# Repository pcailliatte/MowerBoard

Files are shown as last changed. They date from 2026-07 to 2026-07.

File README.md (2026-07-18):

# MowerBoard

<p align="center">
  
  
  
  
  
</p>

---

**MowerBoard** est une unité de contrôle électronique (ECU) alternative, robuste et 100% open-source pour tracteurs tondeuses autoportées thermiques.

L'objectif principal de ce projet est de fournir une solution logicielle et matérielle entièrement libre. En mettant à disposition l'intégralité des schémas de conception, des fichiers de fabrication et du code source, nous démocratisons l'accès à une technologie généralement propriétaire et verrouillée par les fabricants.

---

<p align="center">
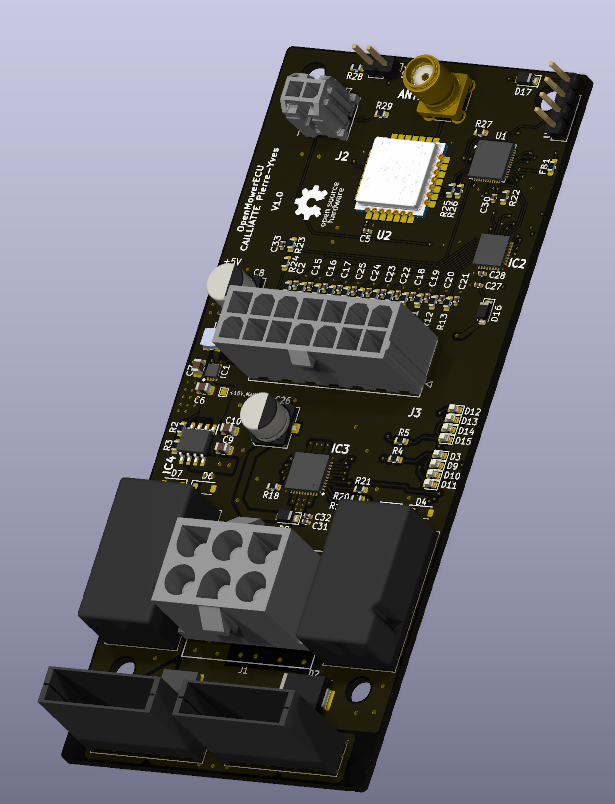
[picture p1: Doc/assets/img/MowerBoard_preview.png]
Aperçu MowerBoard
  
</p>

---

## ⚡ À Propos de ce Projet

> **⚠️ Important :** Je suis un **maker amateur passionné par l'électronique**, pas un professionnel de l'ingénierie ni de la motoculture. 
> 
> Ce projet est développé **sur mon temps libre** et représente mon apprentissage et mes expériences personnelles. **Il peut contenir des erreurs de conception, des mauvaises pratiques ou des défauts** que je ne pourrais pas identifier seul.
>
> Je partage ce travail dans un esprit collaboratif et éducatif. Si tu utilises ce projet, sois conscient que :
> - La conception peut ne pas être optimale
> - Il n'y a pas de validation professionnelle ou de certification
> - Des améliorations et corrections peuvent être nécessaires
> - **Toute erreur reste ta responsabilité personnelle**
> - Le support n'est disponible que sur la base du temps libre disponible
>
> **Je t'encourage vivement à faire review ta réalisation par un professionnel** avant une utilisation critique.

---

## 📋 Table des matières

- [À Propos de ce Projet](#-à-propos-de-ce-projet)
- [Machine Cible](#-machine-cible)
- [État du projet](#-état-du-projet)
- [Caractéristiques principales](#-caractéristiques-principales)
- [Spécifications techniques](#-spécifications-techniques)
- [Télémétrie & Home Assistant](#-télémétrie--home-assistant)
- [Coût estimé](#-coût-estimé)
- [Installation & Démarrage](#-installation--démarrage)
- [Structure du projet](#-structure-du-projet)
- [Clause de non-responsabilité](#-clause-de-non-responsabilité--risques-critiques)
- [Licence](#-licence)
- [Contributions](#-contributions--état-du-projet)

---

## 🎯 Machine Cible

**MowerBoard** a été conçu et développé pour : **STAUB BLIZZARD 107 L 16 KH (2019)**

- **Moteur :** EMAK K1600 AVD (16 ch, 452 cm³)
- **Année :** 2019
- **Tension système :** 12V batterie

Cette ECU remplace le contrôleur d'origine de ce tracteur de pelouse, offrant une solution open-source robuste et facilement hackable.

### Portabilité & Forks

Bien que spécifiquement adapté au STAUB BLIZZARD 107 L, le design modulaire permet des adaptations pour d'autres tracteurs de pelouse avec architecture similaire.

Si tu adaptes pour un autre modèle, crée un fork et documente tes changements ! 🍴

---

## 🚦 État du projet

| Aspect | Statut |
|---|---|
| **Statut global** | 🛠️ Développement en cours |
| **Phase actuelle** | 🧪 Version alpha |
| **Hardware** | ✅ Saisie terminée (KiCad 10) |
| **Firmware** | 🔄 Écriture initiale en cours (C brut, microcontrôleur AVR) |
| **Structure du dépôt** | 🔄 Organisation en cours |
| **Documentation** | 🔄 En cours |
| **Release stable** | ⏳ Non disponible |

---

## 🚀 Caractéristiques principales

*   **✨ Matériel et Code 100% Libres :** Accès total aux schémas électroniques, fichiers de routage (PCB) et code source du firmware sans restriction d'accès. Inspiré par la philosophie du mouvement open-source.

*   **🛡️ Architecture Robuste :** Conçu spécifiquement pour l'environnement difficile d'un véhicule thermique (vibrations, parasites électromagnétiques induits par l'allumage, variations de tension de batterie, humidité).

*   **🔒 Logique de Sécurité Centralisée :** Gestion stricte et déterministe des boucles de sécurité critiques :
    - Détection de présence siège
    - Engagement/désengagement des lames
    - Position du point mort
    - Frein de parking
    - Arrêt d'urgence matériel
    - **Failsafe matérielle** : DO_EN en pulldown → coupage automatique des sorties en cas de watchdog

*   **⚡ Contrôle de Puissance Intégré :** Commande directe des actionneurs avec protections adaptées :
    - Embrayage électromagnétique de lame
    - Solénoïde de démarreur
    - Gestion thermique et overcurrent

*   **📊 Diagnostic & Télémétrie LoRa :** Support des interfaces de communication pour logging et diagnostic :
    - Communication série UART
    - **Télémétrie longue portée via LoRa** (Wio-E5-LE de Seeed en modem)
    - Monitoring à distance et diagnostics temps-réel (non-critique pour la sécurité)
    - **Intégration Home Assistant** pour domotique locale

*   **💰 Solution Économique :** Coût matériel estimé **~100€** pour fabriquer une carte (bien inférieur aux solutions propriétaires commerciales)

---

## 🛠 Spécifications Techniques

Le projet est divisé en deux domaines totalement ouverts :

### Architecture

*   **Cœur temps-réel :** AVR128DB (boucles de sécurité déterministes, contrôle des actionneurs)
*   **Modem LoRa :** Wio-E5-LE de Seeed (télémétrie optionnelle, non-critique)
*   **Failsafe matérielle :** DO_EN en pulldown garantit l'arrêt en cas de défaillance du MCU

### Hardware (Matériel)

*   **Outil de conception :** KiCad 10
*   **Fichiers fournis :**
    - Schémas de principe détaillés
    - Routage de puissance et signaux
    - Nomenclature complète (BOM)
    - Fichiers Gerber (prêts pour fabrication PCB)
*   **Microcontrôleur principal :** AVR128DB
*   **Module LoRa :** Wio-E5-LE de Seeed (STM32WLE5xx)
*   **Tensions supportées :** 12V batterie, régulation embarquée

### Firmware (Code)

*   **Langage :** C brut (pas de couche d'abstraction matérielle)
*   **Compilateur :** MPLAB X / XC Compiler
*   **Caractéristiques :**
    - Boucles de sécurité déterministes temps-réel
    - Gestion des modes de veille (économie d'énergie)
    - Communication séries (UART)
    - Watchdog matériel et software
    - Failsafe électronique : perte de contrôle → arrêt automatique

### Module LoRa (Télémétrie)

*   **Module :** Seeed Wio-E5-LE (fonctionne en modem indépendant)
*   **Protocole :** LoRaWAN / LoRa
*   **Fonction :** Transmission longue portée des données de diagnostic et de télémétrie
*   **Avantages :** 
    - Portée jusqu'à plusieurs kilomètres
    - Faible consommation énergétique
    - Non-critique pour la sécurité (arrêt indépendant du LoRa)

---

## 📱 Télémétrie & Home Assistant

Le module LoRa transmet les données de la tondeuse vers une gateway LoRaWAN locale, intégrée dans **Home Assistant**.

### Données remontées

**Phase 1 (MVP) :**
- **Horamètre** : Cumul des heures de fonctionnement
- **Tension batterie** : État de charge et diagnostic

**Phase 2 (futur) :**
- Température moteur
- Cycle des lames
- Diagnostics avancés

### Architecture

```
ECU (Wio-E5-LE) 
    ↓ LoRa
Gateway LoRaWAN Seeed
    ↓ Ethernet/WiFi
Home Assistant (local)
    ↓
Dashboard / Alertes / Automations
```

### Utilité

- **Monitoring à distance** : Suivi de l'état depuis le canapé
- **Historique** : Logs des heures de tonte
- **Alertes** : Notification si batterie faible, etc.
- **Automations** : Intégration avec d'autres services domotiques

> **Note :** La télémétrie est **optionnelle et non-critique**. La tondeuse fonctionne normalement même si le LoRa est déconnecté.

---

## 💰 Coût estimé

**Coût de fabrication prévu : ~100€** (pour une carte complète, pièce unique)

Cette estimation inclut :
- PCB (fabrication industrielle)
- Composants électroniques (résistances, condensateurs, ICs)
- Module LoRa Wio-E5-LE
- Connecteurs et éléments passifs
- Régulateur 12V et protections

**Cette solution est significativement moins coûteuse que les ECU propriétaires du marché**, tout en offrant des capacités équivalentes ou supérieures.

> **Note :** Le coût peut varier selon les fournisseurs, les quantités commandées et les taux de change. Cette estimation est basée sur les prix courants des composants (2024). En production de volume, le coût pourrait être réduit.

---

## 🚀 Installation & Démarrage

### Prérequis

**Pour le Hardware :**
- KiCad 10.0+
- Outils de fabrication PCB (si fabrique soi-même)
- Composants électroniques (voir BOM)

**Pour le Firmware :**
- MPLAB X IDE
- Compiler XC8 (Microchip)
- Programmateur AVR (ex : PICKIT5)

**Pour la Télémétrie (optionnel) :**
- Home Assistant (installation locale)
- Gateway LoRaWAN Seeed (WM1302, etc.)

### Étapes de mise en place

#### 1. Cloner le dépôt
```bash
git clone https://github.com/pcailliatte/MowerBoard.git
cd MowerBoard
```

#### 2. Hardware - Fabriquer la carte
- Ouvrir les fichiers KiCad dans `Hardware/`
- Exporter les fichiers Gerber
- Envoyer à un fabricant PCB (ex : JLCPCB, PCBway)
- Souder les composants (voir BOM pour la liste complète)

#### 3. Firmware - Compiler et flasher
```bash
cd Firmware/
mplab build
# Programmer via AVR ISP
```

#### 4. Télémétrie (optionnel)
- Configurer la gateway LoRaWAN dans Home Assistant
- Flasher le firmware LoRa sur le Wio-E5-LE
- Ajouter les sensors dans Home Assistant

---

## 📁 Structure du projet

⚠️ **La structure du dépôt est actuellement en cours d'organisation. Les chemins et répertoires ci-dessous reflètent la vision finale du projet.**

```
MowerBoard/
├── Hardware/
│   ├── STAUB_BLIZZARD_107L/
│   │   ├── Schematics/      # Schémas électroniques KiCad
│   │   ├── PCB/             # Fichiers de routage et Gerber
│   │   ├── BOM.csv          # Nomenclature des composants
│   │   └── Doc/             # Documentation hardware spécifique
│   └── Generic/             # Composants réutilisables pour autres modèles
├── Firmware/
│   ├── src/                 # Code source C
│   ├── include/             # En-têtes
│   ├── Makefile             # Build configuration
│   └── Doc/                 # Documentation firmware
├── LoRa/
│   ├── src/                 # Code LoRa / Wio-E5-LE
│   ├── telemetry/           # Schéma de télémétrie
│   └── Doc/                 # Documentation LoRa & Home Assistant
├── Doc/
│   ├── assets/              # Images et ressources
│   ├── DESIGN.md            # Rationale de conception
│   ├── ASSEMBLY.md          # Guide d'assemblage
│   ├── SAFETY.md            # Guides de sécurité
│   └── COMPATIBILITY.md     # Compatibilité avec autres modèles
├── README.md                # Ce fichier
├── CONTRIBUTING.md          # Guide de contribution
└── LICENCE.MD               # Texte complet de la licence

```

---

## ⚠️ Clause de Non-Responsabilité & Risques Critiques

### 🚨 DANGER DE MORT ET DE BLESSURES GRAVES

Un tracteur tondeuse est une machine lourde dotée d'un plateau de coupe rotatif à haute vitesse. **Vos actions de conception, de soudure, de câblage, de programmation et d'intégration de cette carte vous engagent personnellement.**

#### Responsabilité absolue de vos actions

*   L'intégration de cette carte, la modification du faisceau électrique d'origine, le flashage du firmware et le **shunt volontaire ou involontaire** des boucles de sécurité construites **relèvent de votre seule responsabilité légale et pénale.**
*   Une défaillance de cette ECU peut entraîner :
    - La perte de contrôle du moteur
    - L'engagement involontaire des lames de coupe
    - La perte du freinage d'urgence
    - **Des blessures graves ou mortelles**

#### Absence de Garantie

Ce projet est fourni **"en l'état"**, à des fins éducatives et de recherche, **sans aucune garantie d'aucune sorte**, expresse ou implicite, quant à sa sécurité, sa fiabilité, sa conformité légale ou son fonctionnement.

#### Limitation de Responsabilité

En aucun cas les auteurs, contributeurs ou titulaires du copyright ne pourront être tenus responsables des dommages directs, indirects, accessoires ou consécutifs (incluant mais non limités aux blessures, décès, dommages matériels) résultant de l'utilisation ou de l'abus de ce projet.

#### Statut du Projet & Expertise

**Je suis un maker amateur passionné par l'électronique**, développant ce projet **sur mon temps libre**, pas un professionnel de l'ingénierie ni de l'industrie agro-mécanique. **Ce projet peut contenir des erreurs de conception, des défauts, ou des mauvaises pratiques** que je n'aurais pas identifiés seul.

**Je te recommande vivement de faire valider ta réalisation par un professionnel qualifié** avant toute utilisation sur une machine réelle.

#### Conformité légale & Assurance

Avant toute intégration :
- ✅ Consultez un ingénieur agréé
- ✅ Vérifiez la conformité réglementaire locale
- ✅ Contactez votre assurance
- ✅ Faites review votre travail par un professionnel
- ✅ Testez exhaustivement dans un environnement isolé et sécurisé

---

## 📜 Licence

Ce projet est publié sous licence **CERN Open Hardware Licence - Strong Reciprocal v2 (CERN-OHL-S v2)**.

### Ce que cela signifie

*   **Partage et Fork :** Vous êtes libre de copier, modifier et distribuer ce projet (schémas, PCB, code).

*   **Attribution :** Vous devez conserver la mention du copyright d'origine et l'attribution au projet MowerBoard dans tous les travaux dérivés.

*   **Usage Commercial :** La fabrication et la vente commerciale de cette carte **sont autorisées**, à condition de respecter les clauses ci-dessous.

*   **Copyleft Fort (Pas de prise de contrôle) :** Si vous modifiez le matériel, les schémas ou le code et que vous les distribuez, **vous avez l'obligation légale de publier l'intégralité de vos modifications** sous la même licence CERN-OHL-S v2.

*   **Aucun droit de marque :** Vous ne pouvez pas utiliser le nom "MowerBoard" pour des produits dérivés sans permission explicite.

**Le texte complet de la licence est disponible dans le fichier `LICENCE.MD`.**

---

## 👥 Contributions

Ce dépôt centralise l'ingénierie partagée du projet. Les schémas, nomenclatures (BOM) et codes sources sont documentés ouvertement au fur et à mesure du développement.

### Comment contribuer ?

1. **Fork le projet** sur GitHub
2. **Créer une branche** (`git checkout -b feature/ma-contribution`)
3. **Soumettre une Pull Request** avec une description claire
4. **Attendre la review** des contributeurs

### Directives de contribution

*   Respectez la structure existante du projet
*   Testez votre code avant de le soumettre
*   Documentez vos changements
*   Utilisez des messages de commit clairs en français ou anglais
*   Respectez la licence CERN-OHL-S v2

### Signalement de bugs

Utilisez l'onglet Issues pour signaler des bugs ou suggérer des améliorations.

**Consultez le fichier `CONTRIBUTING.md` pour des directives détaillées.**

---

## 📚 Documentation supplémentaire

- [Guide de contribution](CONTRIBUTING.md)
- [Guide d'assemblage](Doc/ASSEMBLY.md)
- [Design & Architecture](Doc/DESIGN.md)
- [Guide de sécurité](Doc/SAFETY.md)
- [Compatibilité & Portabilité](Doc/COMPATIBILITY.md)
- [FAQ & Troubleshooting](Doc/FAQ.md)

---

## 🔗 Ressources externes

*   [KiCad Documentation](https://docs.kicad.org/)
*   [CERN Open Hardware Licence](https://ohwr.org/cern_ohl_v2_how_to_use.pdf)
*   [Microchip AVR Documentation](https://www.microchip.com/)
*   [Seeed Wio-E5-LE Documentation](https://wiki.seeedstudio.com/Wio_E5_series_LoRa_Module/)
*   [Home Assistant Documentation](https://www.home-assistant.io/)
*   [Seeed LoRaWAN Gateway](https://wiki.seeedstudio.com/Gateway_LoRaWAN/)

---

## ✉️ Contact & Support

*   **Issues GitHub :** Pour les bugs et questions techniques
*   **Discussions GitHub :** Pour les échanges communautaires

---

**Dernière mise à jour :** Juillet 2026
**Maintaineur :** [@pcailliatte](https://github.com/pcailliatte) (maker amateur passionné développant sur temps libre)

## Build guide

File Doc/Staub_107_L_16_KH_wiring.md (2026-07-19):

# Câblage — Power plug et Command Plug

Rétro-ingénierie du câblage d'alimentation de l'ECU MowerBoard sur le Staub 107 L 16 KH.

## Power socket (prise d'alimentation)

- Prise d'alimentation :
<p align="center">
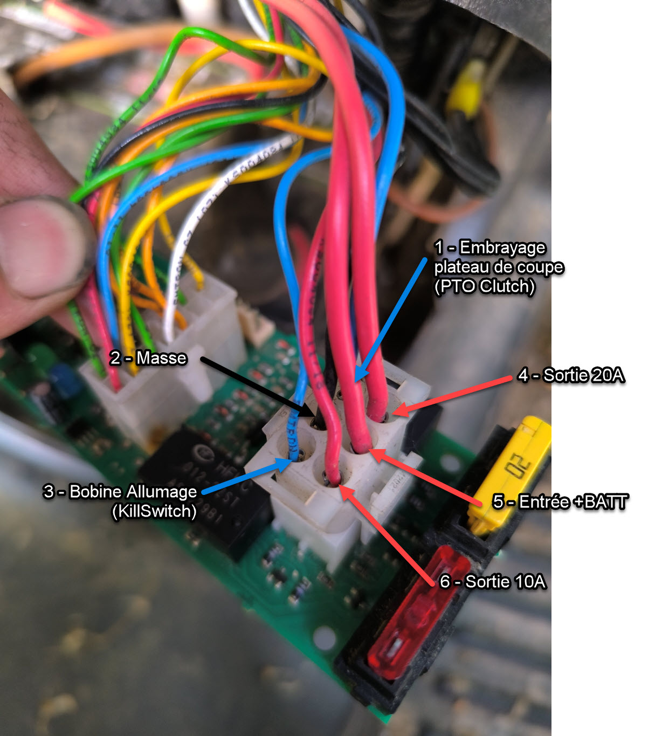
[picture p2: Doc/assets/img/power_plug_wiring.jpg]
Power Socket
  
</p>
  ![Power plug wiring]()

| Broche | Fonction | Couleur du fil | Tension | Notes |
|---|---|---|---|---|
| 1 | Embrayage plateau de coupe | Bleu | GND pour activer | Bobine 2 relais K1 |
| 2 | Masse | Noir | GND | |
| 3 | Kill Switch moteur | Bleu | GND = moteur OFF | Bobine 1 relais K1 - NC sur GND (sécurité) |
| 4 | Sortie carte (fusible 20A) | Rouge | +12V | |
| 5 | Entrée batterie | Rouge | +12V | |
| 6 | Sortie carte (fusible 10A) | Rouge | +12V | |

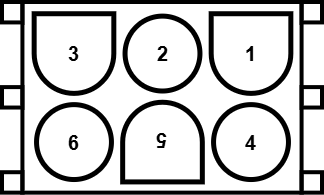
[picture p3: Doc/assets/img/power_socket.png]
Power Socket
  

## Connecteur 2x7 pin Molex (14 broches)

- Prise de commandes :
<p align="center">
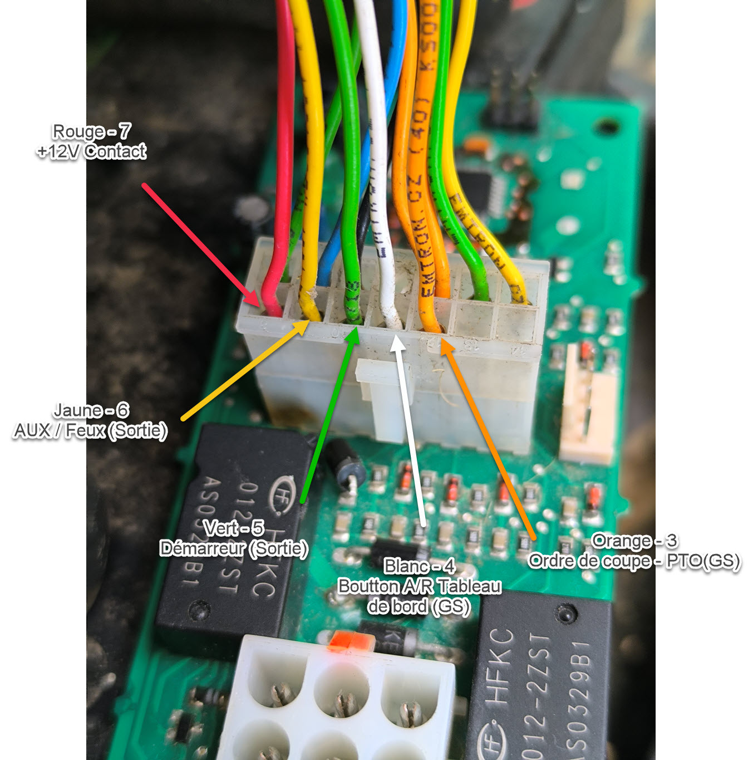
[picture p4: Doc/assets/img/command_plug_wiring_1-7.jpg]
Command Socket
  
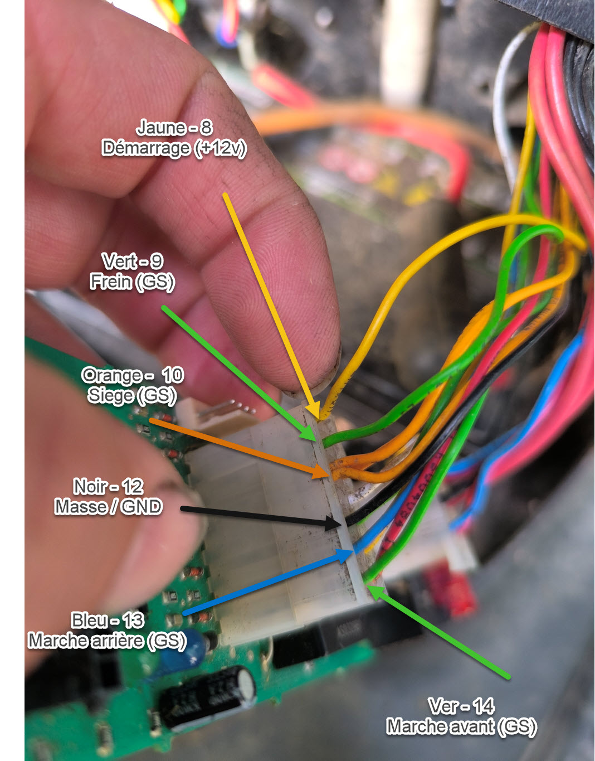
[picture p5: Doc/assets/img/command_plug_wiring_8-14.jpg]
Command Socket
  
</p>

Numérotation :
- Rangée A : broches 1→7
- Rangée B : broches 8→14

| Broche | Signal / Fonction | Direction | Couleur | Tension | Notes |
|---:|---|---|---|---|---|
| 1 | Non connecté | NC | | | |
| 2 | Non connecté  | NC | | | |
| 3 | Ordre de coupe / PTO | INPUT | Orange | Commutation de masse | |
| 4 | Bouton A/R sur tableau de bord | INPUT | Blanc | Commutation de masse | Historiquement le dévérouillage de la coupe en arrière |
| 5 | Masse de la solénoïde du démarreur| OUTPUT | Vert | GND = Démarrage | Via relais K1 bobine 1 |
| 6 | AUX / Feux | OUTPUT | Jaune | +12v ou GND fonction du relais | Pas vraiment utilisé, via bobine K2 bobine 2 |
| 7 | Tension de contact (Neiman) | INPUT/POWER | Rouge | +12v | Historiquement alimentation de la carte |
| 8 | Demande de démarrage | INPUT | Jaune | +12v | +12v viens du contact Neiman|
| 9 | Freins | INPUT | Vert | Commutation de masse | Le frein peut être vérouillé fermé |
| 10 | Contact siege | INPUT | Orange | Commutation de masse | |
| 11 | Non connecté | NC | | | |
| 12 | Masse / GND |POWER | Noir | | |
| 13 | Marche arrière | INPUT | Bleu | Commutation de masse | |
| 14 | Marche avant | INPUT | Vert | Commutation de masse | |

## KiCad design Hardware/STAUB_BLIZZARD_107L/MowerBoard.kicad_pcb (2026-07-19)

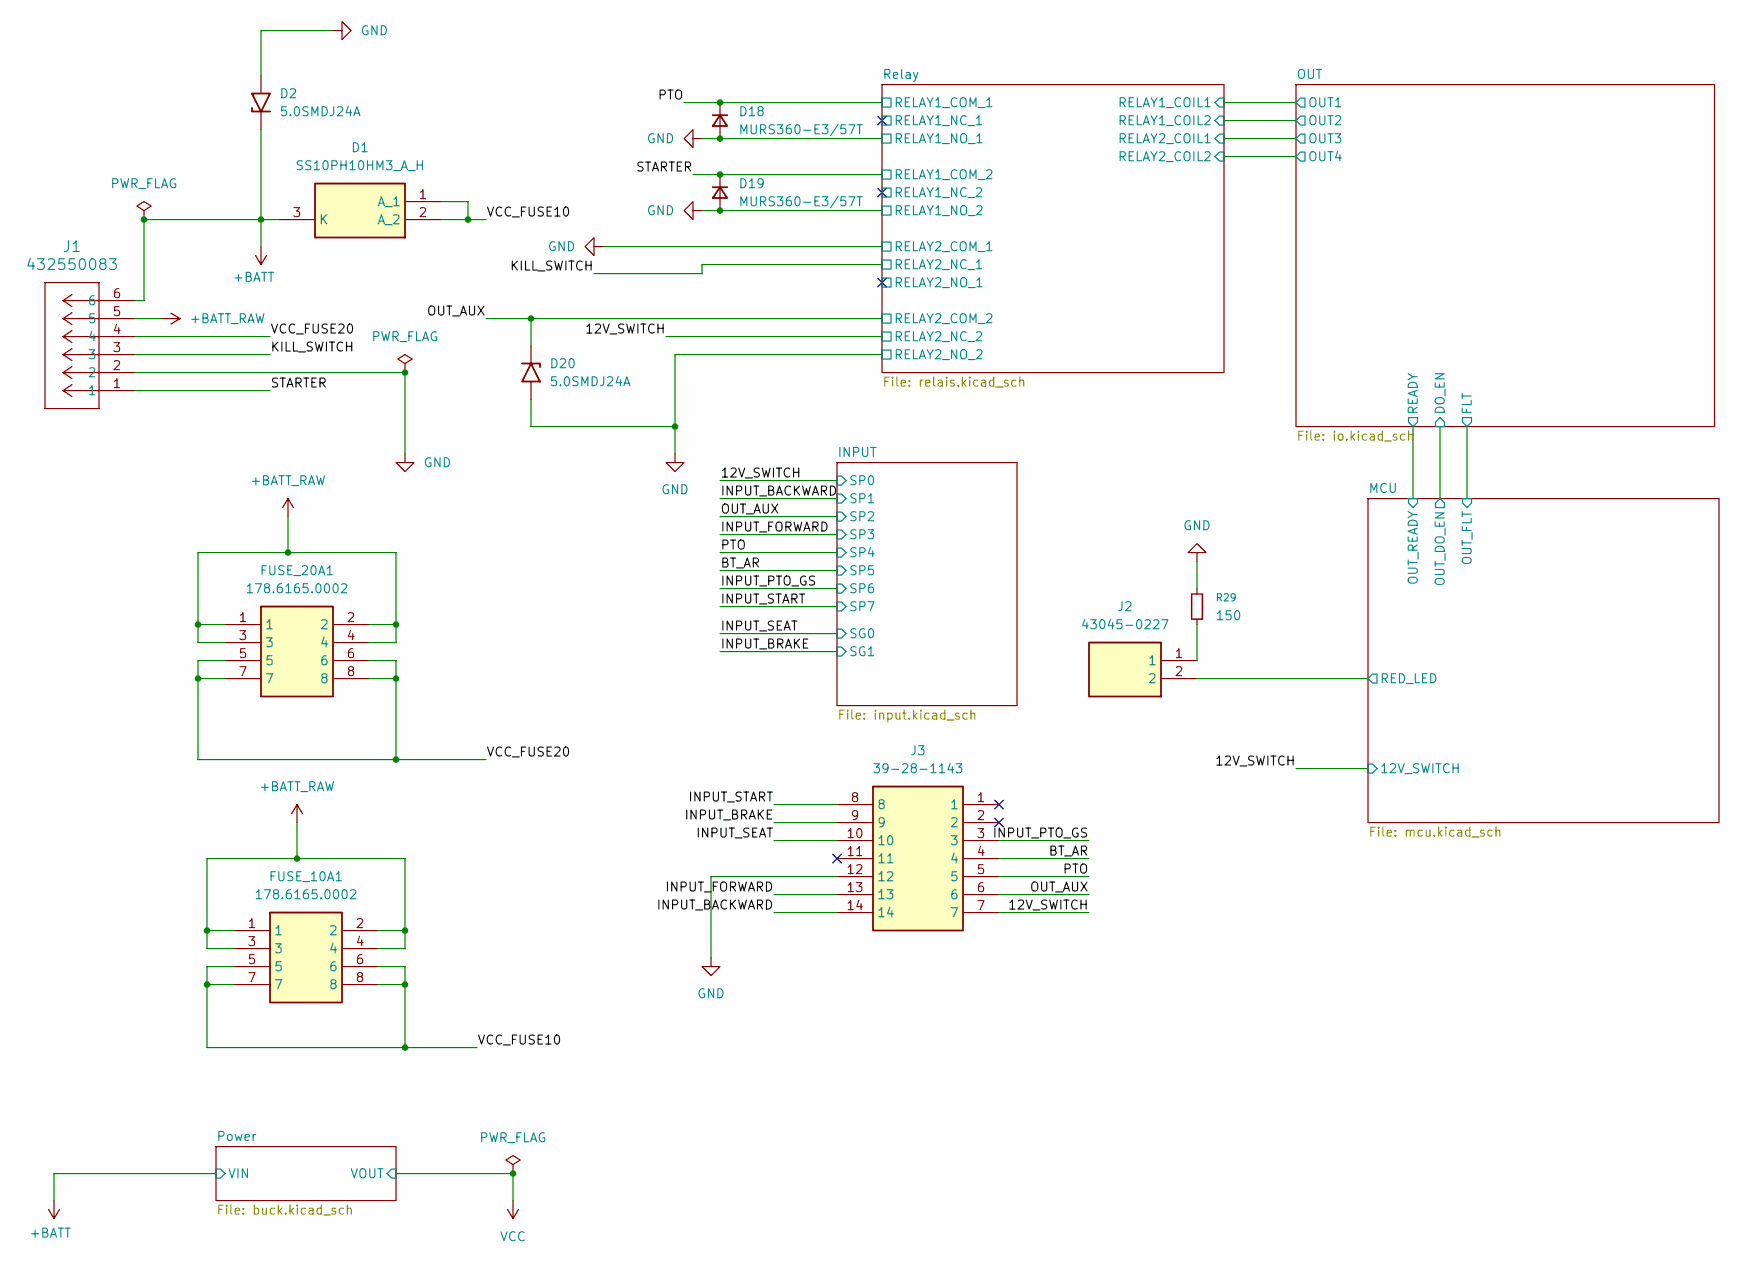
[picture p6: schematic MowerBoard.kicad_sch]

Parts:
D1: SS10PH10HM3_A_H; V10PN50M387A; Mouser Part Number 78-SS10PH10HM3_A/H
D2, D20: 5.0SMDJ24A; D_SMC; Mouser Part Number 576-5.0SMDJ24A
D18, D19: MURS360-E3/57T; D_SMC
FUSE_10A1, FUSE_20A1: 178.6165.0002; 17861650002; Mouser Part Number 576-178.6165.0002
J1: 432550083; CONN_SDA_43255-00xx_06_MOL
J2: 43045-0227; 43045-02YY_272829; Mouser Part Number 538-43045-0227
J3: 39-28-1143; Mouser Part Number 538-39-28-1143
R29: 150; R_0603_1608Metric

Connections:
+BATT: D1.3 (K), D2.1 (A1), J1.6; also elsewhere on the board
+BATT_RAW: FUSE_10A1.1, FUSE_10A1.2, FUSE_10A1.3, FUSE_10A1.4, FUSE_20A1.1, FUSE_20A1.2, FUSE_20A1.3, FUSE_20A1.4, J1.5
/12V_SWITCH: J3.7; also elsewhere on the board
/BT_AR: J3.4; also elsewhere on the board
/INPUT_BACKWARD: J3.14; also elsewhere on the board
/INPUT_BRAKE: J3.9; also elsewhere on the board
/INPUT_FORWARD: J3.13; also elsewhere on the board
/INPUT_PTO_GS: J3.3; also elsewhere on the board
/INPUT_SEAT: J3.10; also elsewhere on the board
/INPUT_START: J3.8; also elsewhere on the board
/KILL_SWITCH: J1.3; also elsewhere on the board
/MCU/RED_LED: J2.2; also elsewhere on the board
/OUT_AUX: D20.1 (A1), J3.6; also elsewhere on the board
/PTO: D18.1 (K), J3.5; also elsewhere on the board
/STARTER: D19.1 (K), J1.1; also elsewhere on the board
/VCC_FUSE10: D1.1 (A_1), D1.2 (A_2), FUSE_10A1.5, FUSE_10A1.6, FUSE_10A1.7, FUSE_10A1.8
/VCC_FUSE20: FUSE_20A1.5, FUSE_20A1.6, FUSE_20A1.7, FUSE_20A1.8, J1.4
GND: D2.2 (A2), D18.2 (A), D19.2 (A), D20.2 (A2), J1.2, J3.12, R29.2; also elsewhere on the board
unnamed: J2.1, R29.1

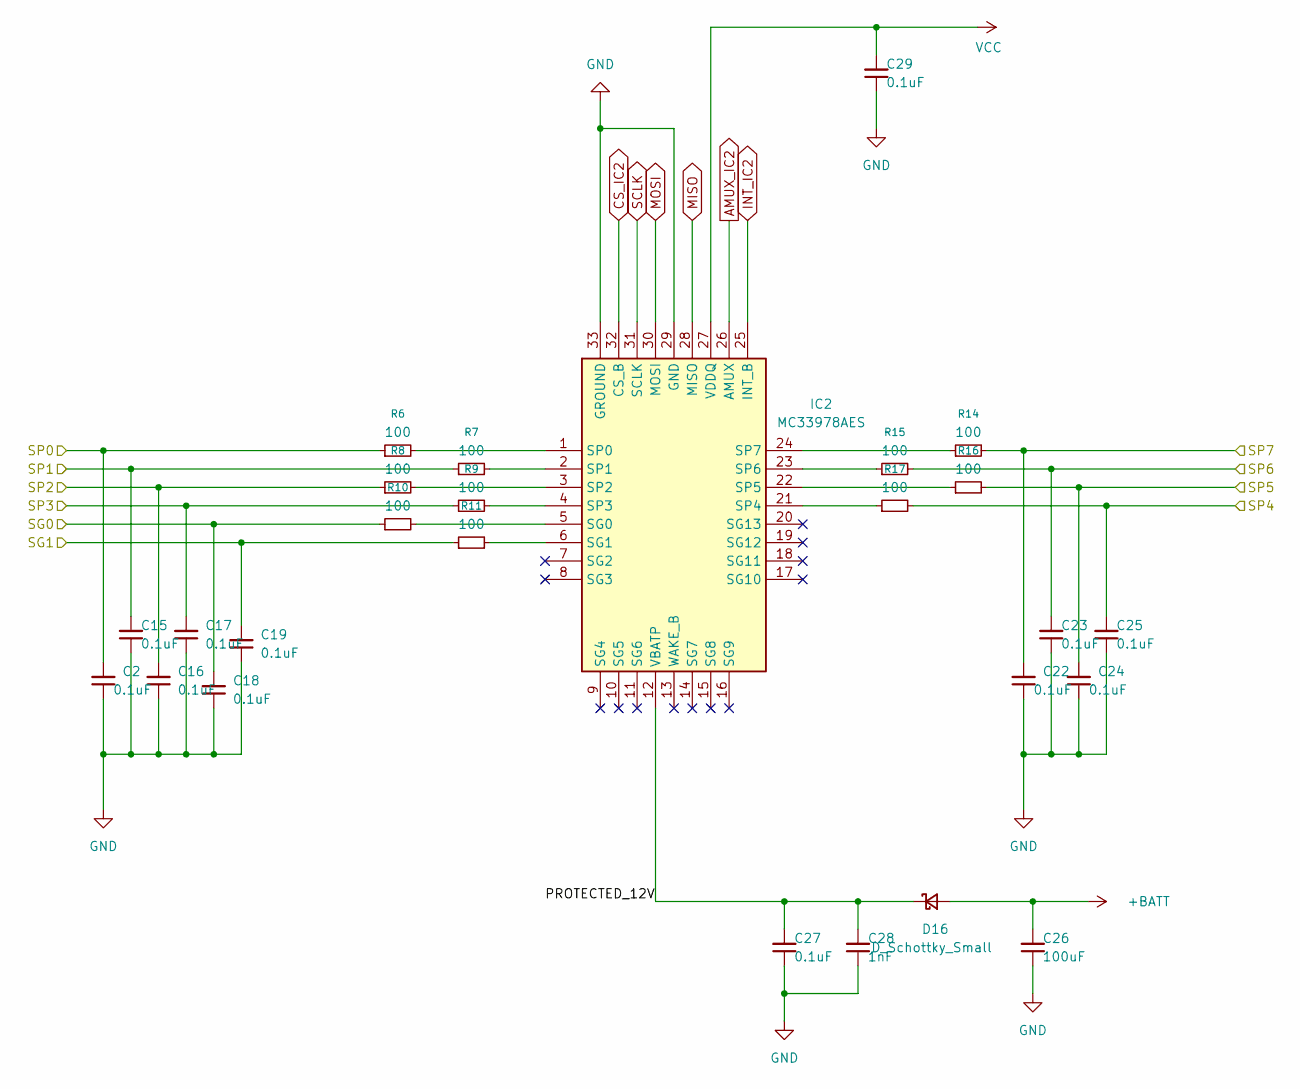
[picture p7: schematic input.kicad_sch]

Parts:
C2, C15, C16, C17, C18, C19, C22, C23, C24, C25, C27, C29: 0.1uF; C_0402_1005Metric
C26: 100uF; CP_Elec_6.3x5.7
C28: 1nF; C_0402_1005Metric
D16: D_Schottky_Small; Nexperia_CFP3_SOD-123W
IC2: MC33978AES; QFN50P500X500X90-33N-D; Mouser Part Number 841-MC33978AES
R6, R7, R8, R9, R10, R11, R14, R15, R16, R17: 100; R_0603_1608Metric

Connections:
+BATT: C26.2, D16.2 (A); also elsewhere on the board
/12V_SWITCH: C2.2, R6.1; also elsewhere on the board
/BT_AR: C24.2, R16.2; also elsewhere on the board
/INPUT/PROTECTED_12V: C27.2, C28.2, D16.1 (K), IC2.12 (VBATP)
/INPUT_BACKWARD: C15.2, R7.1; also elsewhere on the board
/INPUT_BRAKE: C19.2, R11.1; also elsewhere on the board
/INPUT_FORWARD: C17.2, R9.1; also elsewhere on the board
/INPUT_PTO_GS: C23.2, R15.2; also elsewhere on the board
/INPUT_SEAT: C18.2, R10.1; also elsewhere on the board
/INPUT_START: C22.2, R14.2; also elsewhere on the board
/OUT_AUX: C16.2, R8.1; also elsewhere on the board
/PTO: C25.2, R17.2; also elsewhere on the board
AMUX_IC2: IC2.26 (AMUX); also elsewhere on the board
CS_IC2: IC2.32 (CS_B); also elsewhere on the board
GND: C2.1, C15.1, C16.1, C17.1, C18.1, C19.1, C22.1, C23.1, C24.1, C25.1, C26.1, C27.1, C28.1, C29.1, IC2.29 (GND), IC2.33 (GROUND); also elsewhere on the board
INT_IC2: IC2.25 (INT_B); also elsewhere on the board
MISO: IC2.28 (MISO); also elsewhere on the board
MOSI: IC2.30 (MOSI); also elsewhere on the board
unnamed: IC2.5 (SG0), R10.2
unnamed: IC2.6 (SG1), R11.2
unnamed: IC2.1 (SP0), R6.2
unnamed: IC2.2 (SP1), R7.2
unnamed: IC2.3 (SP2), R8.2
unnamed: IC2.4 (SP3), R9.2
unnamed: IC2.21 (SP4), R17.1
unnamed: IC2.22 (SP5), R16.1
unnamed: IC2.23 (SP6), R15.1
unnamed: IC2.24 (SP7), R14.1
SCLK: IC2.31 (SCLK); also elsewhere on the board
VCC: C29.2, IC2.27 (VDDQ); also elsewhere on the board

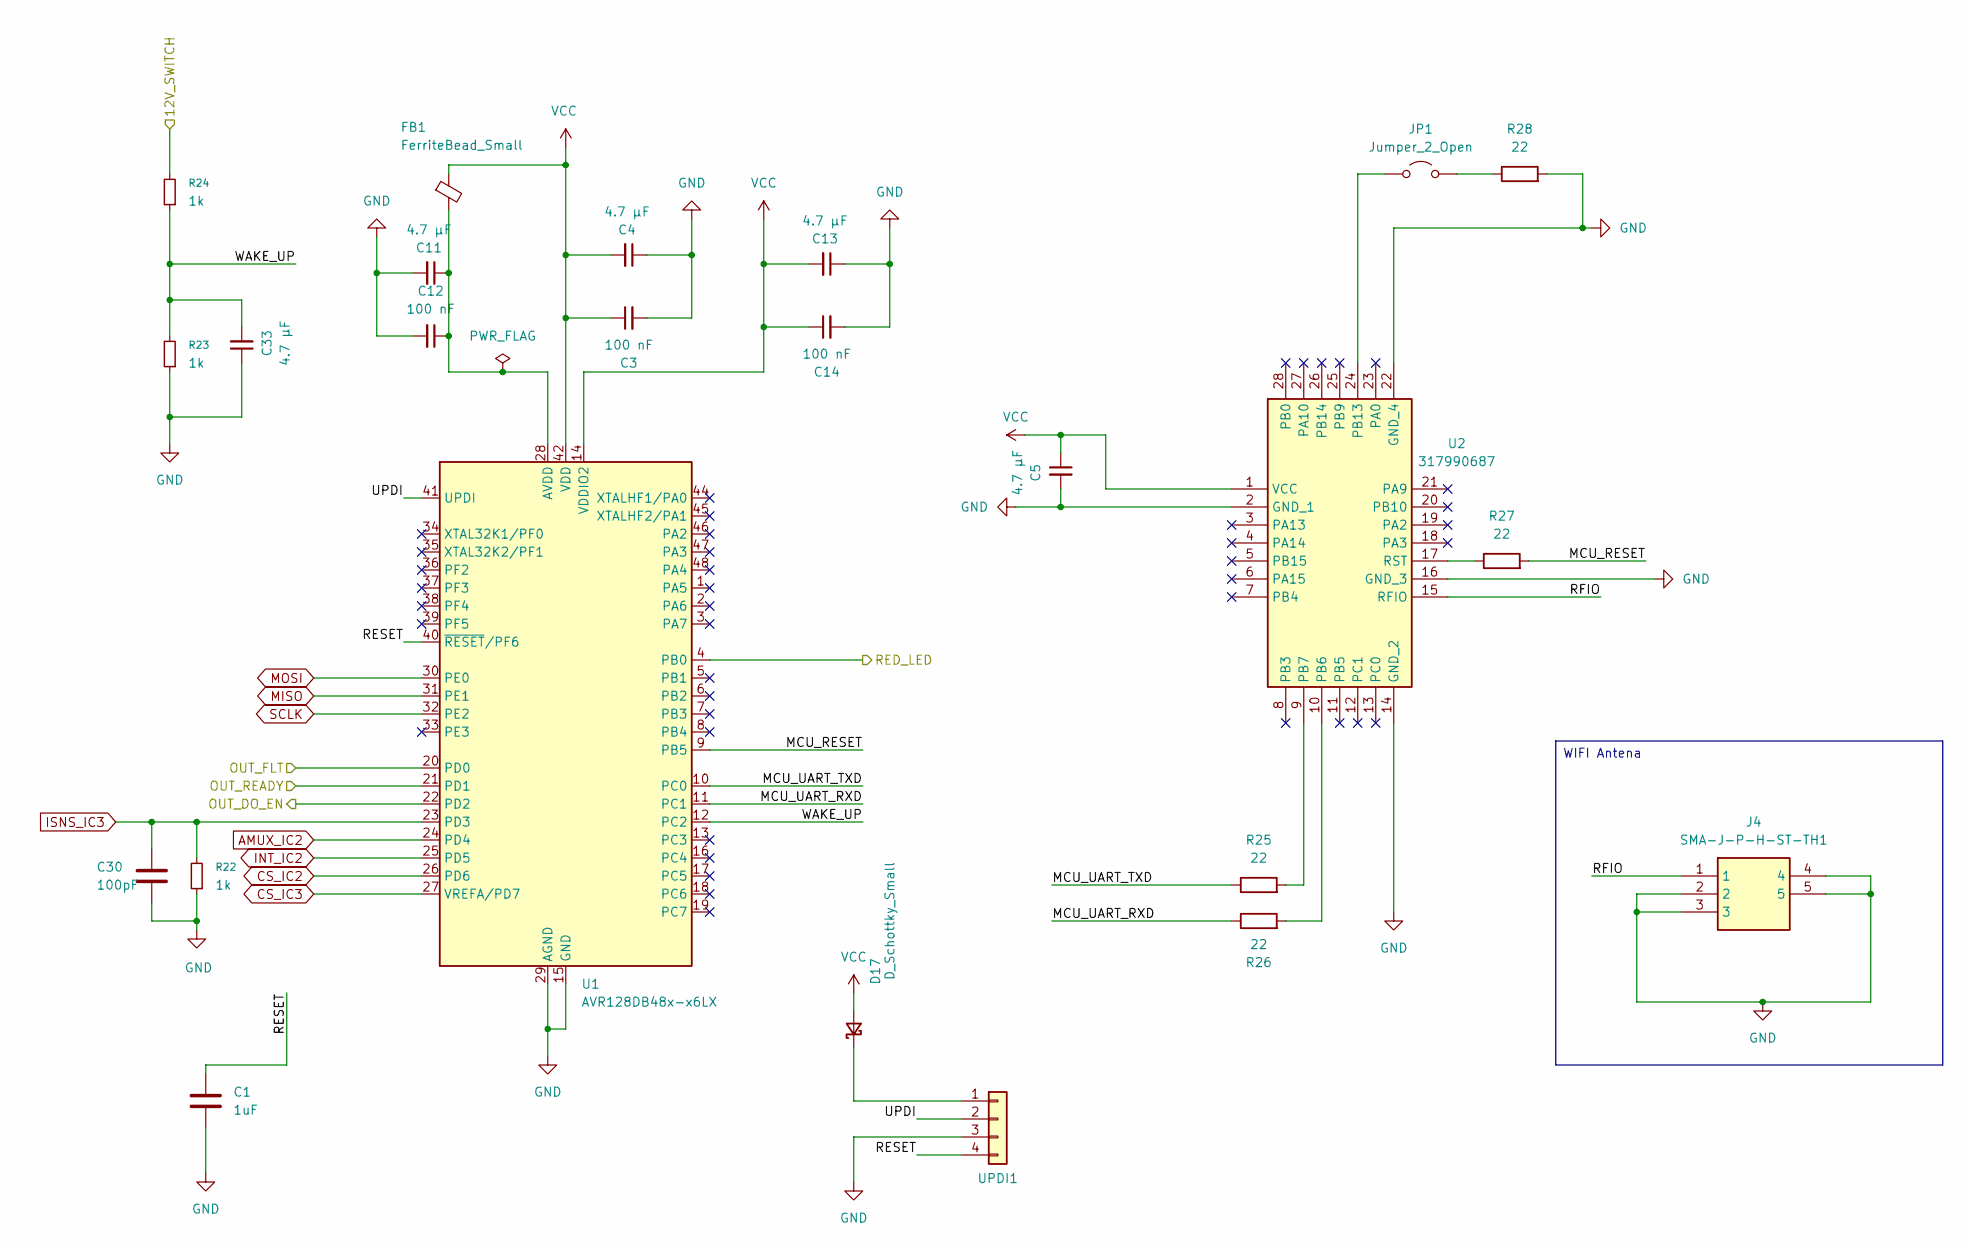
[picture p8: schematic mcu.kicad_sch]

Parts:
C1: 1uF; C_0402_1005Metric
C3, C12, C14: 100 nF; C_0402_1005Metric
C4, C5, C11, C13, C33: 4.7 µF; C_0402_1005Metric
C30: 100pF; C_0402_1005Metric
D17: D_Schottky_Small; Nexperia_CFP3_SOD-123W
FB1: FerriteBead_Small; R_0603_1608Metric_Pad0.98x0.95mm_HandSolder
J4: SMA-J-P-H-ST-TH1; SMAJPHSTTH1; Mouser Part Number 200-SMAJPHSTTH1
JP1: Jumper_2_Open; PinHeader_1x02_P2.54mm_Vertical
R22, R23, R24: 1k; R_0603_1608Metric
R25, R26, R27, R28: 22; R_0603_1608Metric
U1: AVR128DB48x-x6LX; QFN-48-1EP_6x6mm_P0.4mm_EP4.2x4.2mm
U2: 317990687; Mouser Part Number 713-317990687
UPDI1: PinHeader_1x04_P2.54mm_Vertical

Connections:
/12V_SWITCH: R24.2; also elsewhere on the board
/MCU/MCU_RESET: R27.2, U1.9 (PB5)
/MCU/MCU_UART_RXD: R26.1, U1.11 (PC1)
/MCU/MCU_UART_TXD: R25.1, U1.10 (PC0)
/MCU/OUT_FLT: U1.20 (PD0); also elsewhere on the board
/MCU/OUT_READY: U1.21 (PD1); also elsewhere on the board
/MCU/RED_LED: U1.4 (PB0); also elsewhere on the board
/MCU/RESET: C1.1, U1.40 (~RESET/PF6), UPDI1.4
/MCU/RFIO: J4.1, U2.15 (RFIO)
/MCU/UPDI: U1.41 (UPDI), UPDI1.2
/MCU/WAKE_UP: C33.2, R23.2, R24.1, U1.12 (PC2)
/OUT/DO_EN: U1.22 (PD2); also elsewhere on the board
AMUX_IC2: U1.24 (PD4); also elsewhere on the board
CS_IC2: U1.26 (PD6); also elsewhere on the board
CS_IC3: U1.27 (VREFA/PD7); also elsewhere on the board
GND: C1.2, C3.2, C4.1, C5.2, C11.2, C12.2, C13.1, C14.2, C30.2, C33.1, J4.2, J4.3, J4.4, J4.5, R22.1, R23.1, R28.2, U1.15 (GND), U1.29 (AGND), U1.43 (GND), U1.49 (GND), U2.2 (GND_1), U2.14 (GND_2), U2.16 (GND_3), U2.22 (GND_4), UPDI1.3; also elsewhere on the board
INT_IC2: U1.25 (PD5); also elsewhere on the board
ISNS_IC3: C30.1, R22.2, U1.23 (PD3); also elsewhere on the board
MISO: U1.31 (PE1); also elsewhere on the board
MOSI: U1.30 (PE0); also elsewhere on the board
unnamed: D17.1 (K), UPDI1.1
unnamed: JP1.1 (A), U2.24 (PB13)
unnamed: JP1.2 (B), R28.1
unnamed: C11.1, C12.1, FB1.2, U1.28 (AVDD)
unnamed: R26.2, U2.10 (PB6)
unnamed: R25.2, U2.9 (PB7)
unnamed: R27.1, U2.17 (RST)
SCLK: U1.32 (PE2); also elsewhere on the board
VCC: C3.1, C4.2, C5.1, C13.2, C14.1, D17.2 (A), FB1.1, U1.14 (VDDIO2), U1.42 (VDD), U2.1 (VCC); also elsewhere on the board

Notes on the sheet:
WIFI Antena

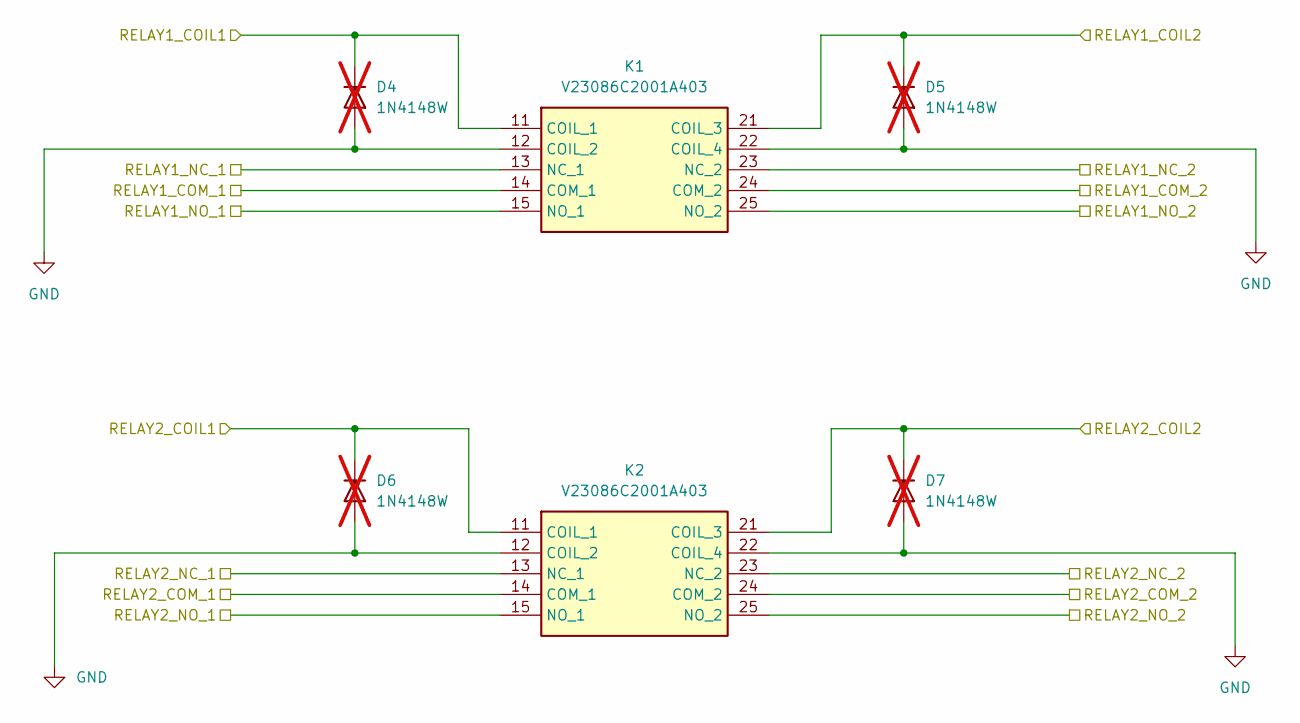
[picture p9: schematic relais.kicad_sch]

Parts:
D4, D5, D6, D7: 1N4148W; D_SOD-123; not fitted
K1, K2: V23086C2001A403; Mouser Part Number 571-1413009-9

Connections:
/12V_SWITCH: K2.23 (NC_2); also elsewhere on the board
/KILL_SWITCH: K2.13 (NC_1); also elsewhere on the board
/OUT/OUT1: D4.1 (K), K1.11 (COIL_1); also elsewhere on the board
/OUT/OUT2: D5.1 (K), K1.21 (COIL_3); also elsewhere on the board
/OUT/OUT3: D6.1 (K), K2.11 (COIL_1); also elsewhere on the board
/OUT/OUT4: D7.1 (K), K2.21 (COIL_3); also elsewhere on the board
/OUT_AUX: K2.24 (COM_2); also elsewhere on the board
/PTO: K1.14 (COM_1); also elsewhere on the board
/Relay/RELAY1_NC_1: K1.13 (NC_1)
/Relay/RELAY1_NC_2: K1.23 (NC_2)
/Relay/RELAY2_NO_1: K2.15 (NO_1)
/STARTER: K1.24 (COM_2); also elsewhere on the board
GND: D4.2 (A), D5.2 (A), D6.2 (A), D7.2 (A), K1.12 (COIL_2), K1.15 (NO_1), K1.22 (COIL_4), K1.25 (NO_2), K2.12 (COIL_2), K2.14 (COM_1), K2.22 (COIL_4), K2.25 (NO_2); also elsewhere on the board

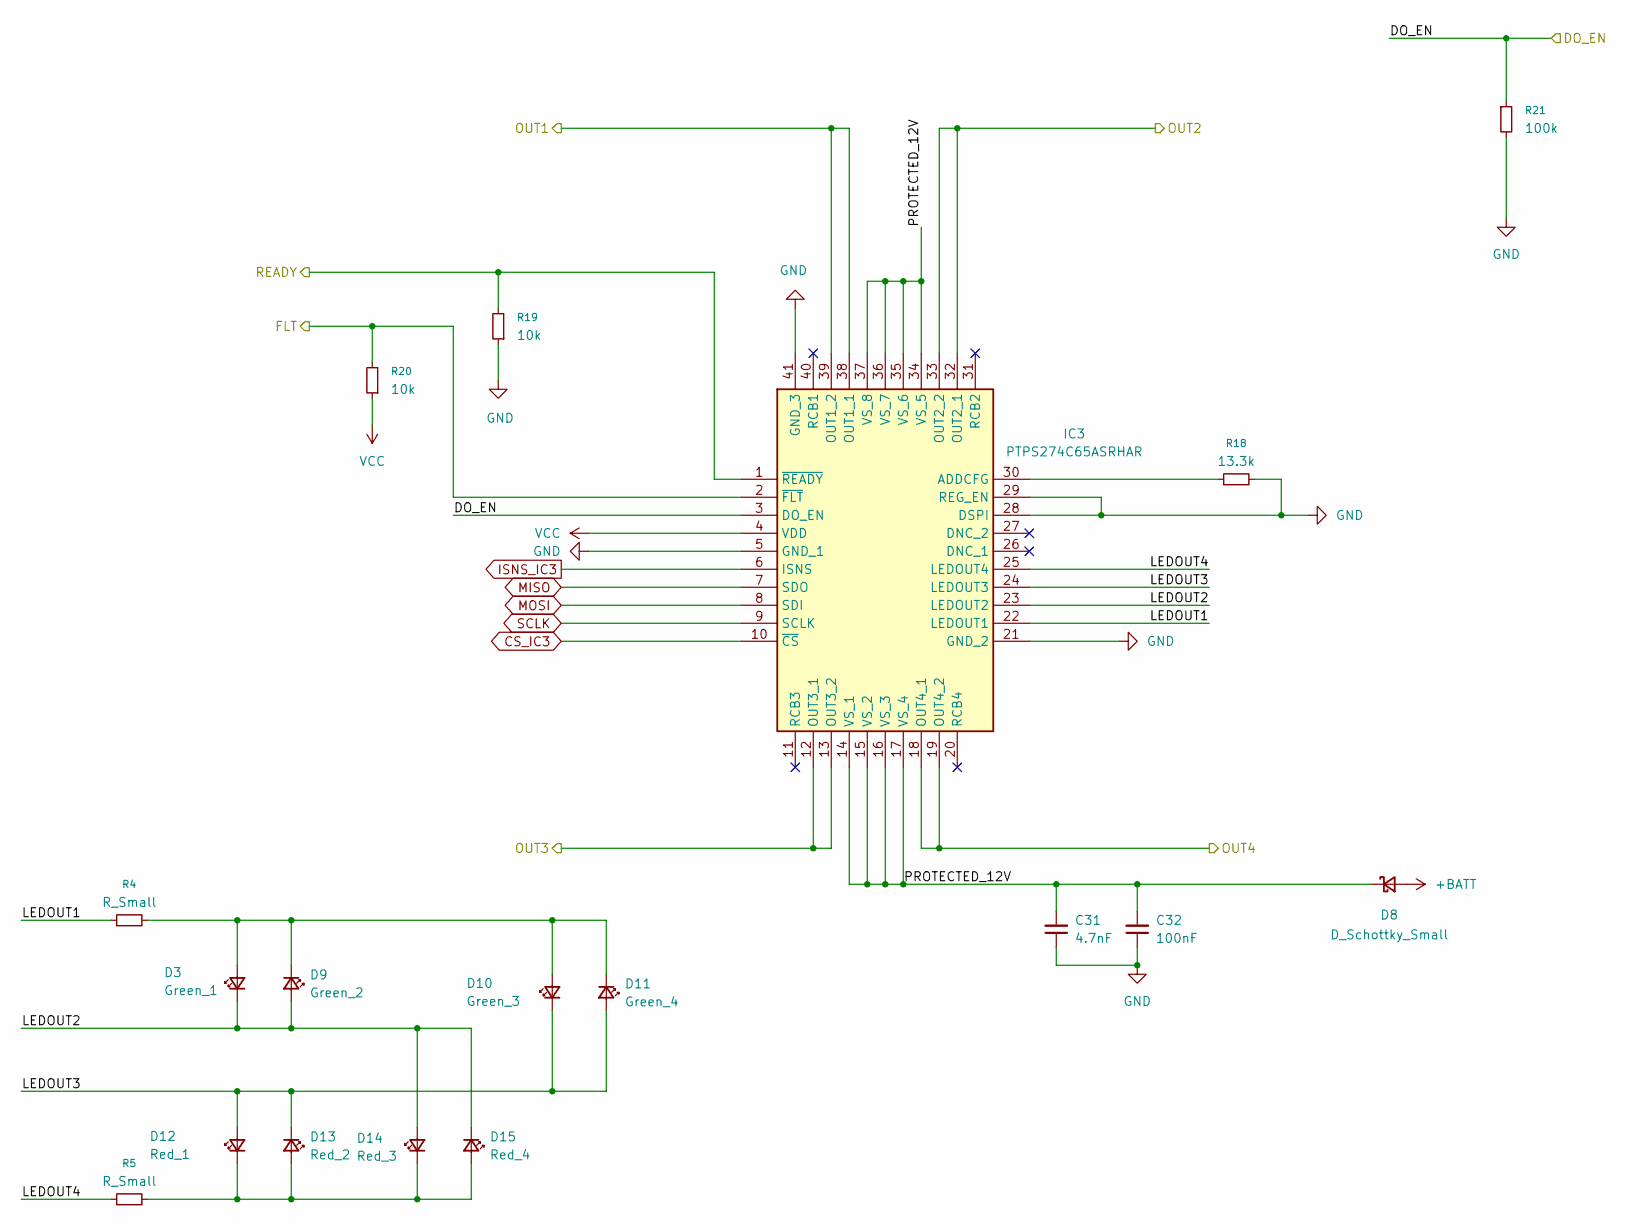
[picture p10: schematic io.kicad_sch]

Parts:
C31: 4.7nF; C_0402_1005Metric
C32: 100nF; C_0402_1005Metric
D3: Green_1; LED_0603_1608Metric
D8: D_Schottky_Small; Nexperia_CFP3_SOD-123W
D9: Green_2; LED_0603_1608Metric
D10: Green_3; LED_0603_1608Metric
D11: Green_4; LED_0603_1608Metric
D12: Red_1; LED_0603_1608Metric
D13: Red_2; LED_0603_1608Metric
D14: Red_3; LED_0603_1608Metric
D15: Red_4; LED_0603_1608Metric
IC3: PTPS274C65ASRHAR; QFN50P600X600X100-41N-D; Manufacturer_Part_Number PTPS274C65ASRHAR
R4, R5: R_Small; R_0603_1608Metric
R18: 13.3k; R_0603_1608Metric
R19, R20: 10k; R_0603_1608Metric
R21: 100k; R_0603_1608Metric

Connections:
+BATT: D8.2 (A); also elsewhere on the board
/MCU/OUT_FLT: IC3.2 (~FLT), R20.2; also elsewhere on the board
/MCU/OUT_READY: IC3.1 (~READY), R19.2; also elsewhere on the board
/OUT/DO_EN: IC3.3 (DO_EN), R21.1; also elsewhere on the board
/OUT/LEDOUT1: IC3.22 (LEDOUT1), R4.1
/OUT/LEDOUT2: D3.1 (K), D9.2 (A), D14.2 (A), D15.1 (K), IC3.23 (LEDOUT2)
/OUT/LEDOUT3: D10.1 (K), D11.2 (A), D12.2 (A), D13.1 (K), IC3.24 (LEDOUT3)
/OUT/LEDOUT4: IC3.25 (LEDOUT4), R5.1
/OUT/OUT1: IC3.38 (OUT1_1), IC3.39 (OUT1_2); also elsewhere on the board
/OUT/OUT2: IC3.32 (OUT2_1), IC3.33 (OUT2_2); also elsewhere on the board
/OUT/OUT3: IC3.12 (OUT3_1), IC3.13 (OUT3_2); also elsewhere on the board
/OUT/OUT4: IC3.18 (OUT4_1), IC3.19 (OUT4_2); also elsewhere on the board
/OUT/PROTECTED_12V: C31.2, C32.2, D8.1 (K), IC3.14 (VS_1), IC3.15 (VS_2), IC3.16 (VS_3), IC3.17 (VS_4), IC3.34 (VS_5), IC3.35 (VS_6), IC3.36 (VS_7), IC3.37 (VS_8)
CS_IC3: IC3.10 (~CS); also elsewhere on the board
GND: C31.1, C32.1, IC3.5 (GND_1), IC3.21 (GND_2), IC3.28 (DSPI), IC3.29 (REG_EN), IC3.41 (GND_3), R18.2, R19.1, R21.2; also elsewhere on the board
ISNS_IC3: IC3.6 (ISNS); also elsewhere on the board
MISO: IC3.7 (SDO); also elsewhere on the board
MOSI: IC3.8 (SDI); also elsewhere on the board
unnamed: D3.2 (A), D9.1 (K), D10.2 (A), D11.1 (K), R4.2
unnamed: D12.1 (K), D13.2 (A), D14.1 (K), D15.2 (A), R5.2
unnamed: IC3.30 (ADDCFG), R18.1
SCLK: IC3.9 (SCLK); also elsewhere on the board
VCC: IC3.4 (VDD), R20.1; also elsewhere on the board

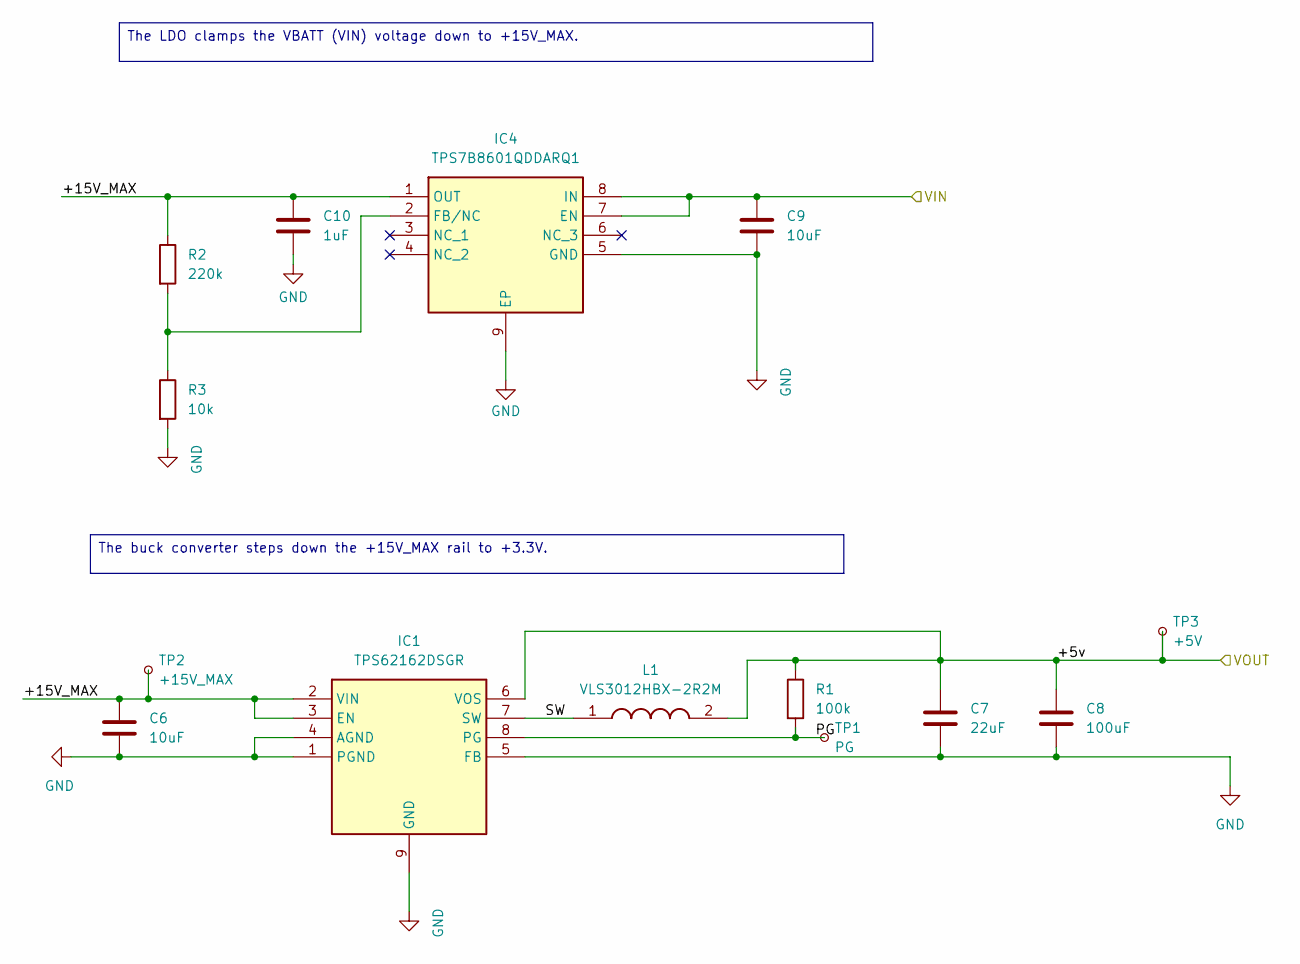
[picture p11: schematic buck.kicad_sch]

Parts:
C6, C9: 10uF; C_0805_2012Metric
C7: 22uF; C_0805_2012Metric
C8: 100uF; CP_Elec_6.3x5.7
C10: 1uF; C_0805_2012Metric
IC1: TPS62162DSGR; SON50P200X200X80-9N; Mouser Part Number 595-TPS62162DSGR
IC4: TPS7B8601QDDARQ1; SOIC127P600X170-9N; Mouser Part Number 595-TPS7B8601QDDARQ1
L1: VLS3012HBX-2R2M; VLS3012; Mouser Part Number 810-VLS3012HBX-2R2M
R1: 100k; R_0603_1608Metric
R2: 220k; R_0603_1608Metric
R3: 10k; R_0603_1608Metric
TP1: PG; TestPoint_Pad_1.0x1.0mm
TP2: +15V_MAX; TestPoint_Pad_1.0x1.0mm
TP3: +5V; TestPoint_Pad_1.0x1.0mm

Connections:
+BATT: C9.1, IC4.7 (EN), IC4.8 (IN); also elsewhere on the board
/Power/+15V_MAX: C6.1, C10.1, IC1.2 (VIN), IC1.3 (EN), IC4.1 (OUT), R2.1, TP2.1 (1_1)
/Power/PG: IC1.8 (PG), R1.2, TP1.1 (1_1)
/Power/SW: IC1.7 (SW), L1.1
GND: C6.2, C7.2, C8.2, C9.2, C10.2, IC1.1 (PGND), IC1.4 (AGND), IC1.5 (FB), IC1.9 (GND), IC4.5 (GND), IC4.9 (EP), R3.2; also elsewhere on the board
unnamed: IC4.2 (FB/NC), R2.2, R3.1
VCC: C7.1, C8.1, IC1.6 (VOS), L1.2, R1.1, TP3.1 (1_1); also elsewhere on the board

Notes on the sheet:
The buck converter steps down the +15V_MAX rail to +3.3V.
The LDO clamps the VBATT (VIN) voltage down to +15V_MAX.

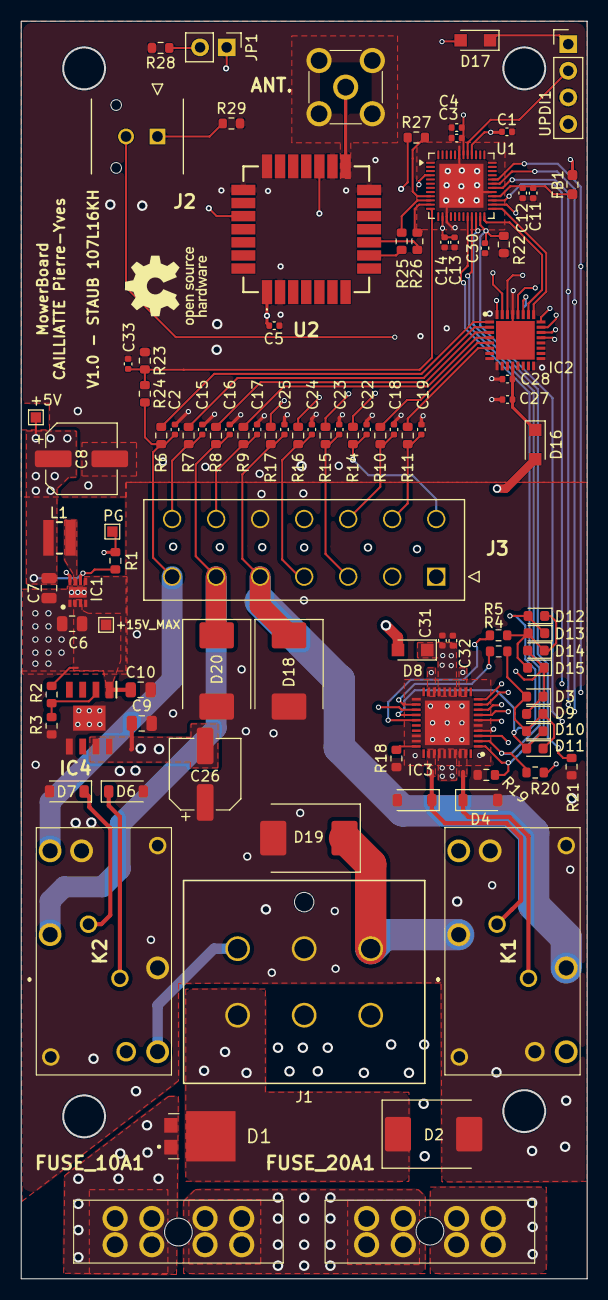
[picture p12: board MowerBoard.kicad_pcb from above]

Board: 4 copper layers, 54.0 x 120.0 mm, 99 parts (1 on the bottom side), 72 nets.

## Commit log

2026-07-19 Mise à jour du descriptif des connecteurs + images
2026-07-19 Mise à jour du nom des pins dans le schématique et reprise du routage. Correction du PCB. Suppresion des SG inutilisés
    [MowerBoard.kicad_pcb, MowerBoard.kicad_sch, input.kicad_sch]
2026-10-25 Précision des licences par domaine (Hardware / Firmware)
2026-10-25 Correction des fautes de frappe dans les noms d'API (Blade, Brake, TPS274C65_*)
